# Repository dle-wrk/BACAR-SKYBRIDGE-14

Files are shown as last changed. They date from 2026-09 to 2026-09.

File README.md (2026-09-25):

# The BACAR Pyramid Payload

**AMSAT SA BACAR-14 "Skybridge" — 17 October 2026**
Contact: Christo Kriek, ZR6LJK — christo.kriek@live.co.za (subject "BACAR")

A natural-light Pepper's Ghost experiment for a high-altitude balloon flight.

---

## What it is trying to do

This payload uses the Earth itself as the light source for an optical illusion
called a Pepper's Ghost, so that a small camera inside a 100 mm cube records
what looks like a floating, three-dimensional image of the Earth below.

Most hologram-pyramid gadgets sit on a desk and reflect a bright video screen.
This one removes the screen entirely. Flown to 25–35 km, it points a single
opening downward at the bright, sunlit Earth. That view *is* the source. A
four-sided clear pyramid reflects it toward a camera, and the camera captures
a floating image formed from real light coming off the planet — no screen, no
power drawn for the image, just optics.

**The question behind it:** can a natural-light Pepper's Ghost capture a
recognisable Earth from the edge of space? Desk versions rely on darkness and
a bright screen. Here the conditions are inverted — the source is far away and
the surroundings are bright. Whether the effect still reads on camera is the
experiment. Success or not, the result is worth recording.

> **Not a hologram.** Real holography needs coherent laser light and
> interference patterns. A pyramid produces a reflection-based floating image —
> visually similar, physically different. "Hologram pyramid" is a popular but
> technically loose name.

---

## The optical principle

Two conditions make a Pepper's Ghost work, and both drive the whole design:

**A bright source against a dark background.** In reflection, black effectively
becomes invisible. Any background light that isn't part of the intended image
shows up as a faint grey box and ruins the illusion. This is why the interior
must be matte black and light-sealed.

**A specific viewpoint.** The floating image only exists when seen through the
reflecting face from the correct angle. The camera has to sit exactly where a
viewer's eye would — it cannot be placed anywhere and "look at the hologram",
because there is no free-floating image to photograph. It must look *at the
reflection in the pyramid face*.

---

## How light travels through the payload

| Step | What happens |
|---|---|
| **1. Entry** | Light from the sunlit Earth travels up through one round aperture in the floor — the only opening that admits image light. Sealed with a clear disc that still passes light. |
| **2. Reflection** | It strikes the inside of one clear acrylic pyramid face, which acts as a partial mirror. |
| **3. Redirection** | The angled face turns the upward light sideways, toward the camera. |
| **4. Capture** | The camera, tilted **18°**, looks at that face and records the floating image. |

### Why 18 degrees

The pyramid faces sit at **54°**, set by the shape of the pre-cut acrylic
panels. A mirror doubles any tilt, so a face 9° steeper than a plain 45° mirror
sends the reflected ray out **18° away from level**. The camera is angled 18°
to look straight back down that reflected path.

The number is forced by the pyramid's geometry, not chosen for looks.

### Why one aperture, not four

An earlier idea used four holes, one per face. It was set aside deliberately:

- **Four holes** — each face reflects a different direction, so the camera sees
  four unrelated views layered on top of each other. Busy, incoherent, and four
  openings to seal against the cold instead of one.
- **One aperture** — a single source produces one clean, coherent floating image
  of whatever is directly below, and only one opening needs sealing.

---

## Structure

A **100 × 100 × 100 mm cube** — the maximum size allowed for the flight — built
from flat panels of **3 mm black acrylic**, laser-cut and glued with acrylic
cement into a light-tight box. Black is essential, not cosmetic: it absorbs
stray light that would otherwise wash out the reflection.

### Panels

| Panel | Features |
|---|---|
| **Floor** | Round light aperture (offset, under the camera's line of sight), sealed clear window, four corner holes for the suspension line, slots locating the pyramid base |
| **Lid** | Pyramid-top support, suspension ring holes, corner string holes matching the floor so the load line runs straight through |
| **Four walls** | Solid and black. Only two carry openings — a small antenna hole, and mounting features for the camera bracket |

### Internal parts

- **The pyramid** — pre-cut four-sided clear acrylic frustum. Base ~85 mm,
  flat top ~9 mm, faces at 54°. Sits base-down on the floor, tip up.
- **Pyramid mounts** — four base clips locate the base; a top support slots
  into the lid and captures the 9 mm tip. Held at both ends.
- **Camera bracket** — two triangular brackets with an 18° top edge, plus a
  flat plate the camera screws to.
- **Electronics** — ESP32-CAM recording to its own card, nRF24 radio,
  MT3608 boost converter, 18650 lithium cell.

**Mass: ~385 g** against a 500 g limit.

---

## Designing for the environment

At 25–35 km the air is thin and temperature falls to around **−50 to −60 °C**.
The payload can't be recovered mid-flight, so it must survive unattended.

**Cold.** The electronics and battery are rated for far milder temperatures
than they'll meet. The box is insulated, a hand-warmer adds heat, and a
silica-gel sachet removes moisture that would otherwise freeze inside.

**Frost.** As the box cools, trapped moisture condenses and can freeze on the
pyramid and lens — directly in the optical path. The sealed window keeps damp
air out; anti-fog treatment helps; keeping the interior warm and dry is the
real defence.

**Landing.** The payload returns under parachute at several metres per second.
Acrylic is brittle in the cold, so glued joints and mounts must take the
impact. Drop-test before flight.

---

## ⚠ Three things that need resolving

These are conflicts between this document and what's currently built. They
are not cosmetic.

### 1. "Airtight" will destroy the box

A sealed enclosure at 30 km carries roughly **1 bar of pressure differential**.
On a 100 × 100 mm panel that's about **1000 N — 100 kgf pushing outward on
every face.** Glued 3 mm acrylic will not hold that, and if it fails it fails
explosively, taking the optics with it.

The frost argument for sealing is real, but the pressure problem is fatal.
The standard resolution is to **vent, but slowly**: a small hole with a
tortuous or filtered path, plus the silica gel already planned. Air equalises
gradually; moist air doesn't rush in. Do not fly this genuinely airtight.

### 2. The 3D-printed enclosure is now obsolete

`holocube.py`, `holocube_fitcheck.py` and the exported STL/STEP files describe
a **printed** cube with the camera on-axis looking down the pyramid's centre.
This document describes a **laser-cut acrylic** cube with the camera tilted
18° looking at a face from the side. They are different machines.

Nothing is lost by keeping the files, but don't print from them expecting the
optics in this document.

### 3. Radio: beacon or downlink?

This document calls the nRF24 "a short-range beacon for recovery". The firmware
currently streams telemetry images over it as well. The streaming version also
functions as a beacon, so there's no conflict in practice — but if the intent
really is beacon-only, the image transmission can be disabled and the cycle
gets shorter.

---

## The flight cycle (~48 s, repeats forever)

```
1. 15 s video clip        -> SD card
2. 1x high-res photo      -> SD card   (UXGA master)
3. 1x low-res photo       -> SD card + streamed over nRF24
4. 30 s pause
```

At 5 m/s ascent that's a full snapshot every **~240 m**, about 125 samples on
the way to 30 km. Set `pause_sec=42` in the config for a 60 s cycle and
exactly 300 m per sample.

| | 3-hour flight |
|---|---|
| Card usage | ~383 MB |
| Average current | ~162 mA |
| Battery used | ~7% of 12 Ah |

Video rolls 15 s out of every 48, so there's roughly a **31% chance of catching
the burst on video**.

### Packet format (32 bytes)

```
[0] type   [1] fragment   [2..31] 30 bytes payload
```

Integrity is the nRF24's **hardware CRC-16** — corrupt packets never arrive.
The end-of-image CRC tells the receiver whether the *reassembly* was complete,
which is a different question. nRF24 carries raw packets, not MQTT; MQTT lives
at mission control, on the far side of the relay.

---

## Pin map — SD and nRF24 share one SPI bus

The camera claims almost every GPIO. These six are all that remain.
**Do not use `SD_MMC`** — it wants these same pins.

| Signal | GPIO |
|---|---|
| SCK | 14 |
| MOSI | 15 |
| MISO | 2 |
| SD chip-select | 13 |
| nRF24 CSN | 12 |
| nRF24 CE | 4 |

---

## Things that will destroy hardware

- **nRF24 VCC → 3V3, never 5V.** No regulator on the module.
- **Set the MT3608 to 5.0 V with a multimeter before connecting the ESP32.**
  It does not ship at 5 V.
- **10 kΩ from IO12 to GND.** Strapping pin — high at boot means the chip
  picks the wrong flash voltage and won't start at all.
- **Capacitor stripe → GND.** Electrolytics vent if reversed.
- **Black tape over the flash LED.** IO4 doubles as that LED and would flood
  the optical chamber on every transmission.

---

## Files

| File | What it is |
|---|---|
| `holocube_selftest/` | **Upload this first.** Checks camera, PSRAM, SD, radio. |
| `holocube_esp32cam/` | Flight firmware. |
| `holocube_receiver_uno/` | Ground receiver for an Arduino Uno. |
| `holocube_rebuild.py` | Reassembles JPEGs from the receiver's serial stream. |
| `holocube.cfg` | **Copy to the SD card root.** Tune exposure and timing without reflashing. |
| `SOLDERING.md` | Bench checklist with three test points. |
| `holocube.py` | *Superseded* — FreeCAD builder for the printed enclosure. |
| `holocube_fitcheck.py` | *Superseded* — collision check for the printed enclosure. |

---

## The honest unknown

The enclosure is the easy part. The box, mounts, sealing and mass budget are
all solved on paper. The single thing that decides whether the payload succeeds
is whether a natural-light Pepper's Ghost actually produces a recognisable
floating Earth on camera — and that cannot be answered by design alone.

**The critical step before committing to the flight is a ground test.** Put the
camera in its mount, aim the sealed aperture at a bright scene with depth, and
record. If the floating image reads on the ground, it will read from altitude.
If it doesn't, that's discovered cheaply on a bench instead of expensively at
30 km.

### Test order

- [ ] **Optical bench test** — does the ghost read at all?
- [ ] **Focus the lens at infinity**, lock it with nail varnish
- [ ] **Tune `aec`** in `holocube.cfg` — exposure is locked and 300 is a guess
- [ ] **Full-duration run** — the whole flight time, armed, exactly as it flies
- [ ] **Freezer test** — one hour assembled and armed
- [ ] **Drop test** — acrylic is brittle cold

On a high-altitude flight, **cold, power and landing cause far more failures
than the optics ever will.** Test in that order.

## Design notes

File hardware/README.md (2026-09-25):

# Skybridge hardware / CAD

FreeCAD scripts that build the printed cube parts as solids and validate
component fit. Run from inside the FreeCAD Python console.

## Scripts

**`holocube.py`** — builds all three printed parts as true solids, exports
STL (print-oriented) and STEP into the parent directory.

```
exec(open(r"C:\path\to\Skybridge14\hardware\holocube.py").read())
```

**`holocube_fitcheck.py`** — drops dimensionally-accurate stand-ins (ESP32-CAM,
NRF24, 18650, boost converter, perspex panels) into the assembly so collisions
and clearances can be sanity-checked. Run **after** `holocube.py`.

```
exec(open(r"C:\path\to\Skybridge14\hardware\holocube_fitcheck.py").read())
```

## Note on output paths

`holocube.py` currently writes STL/STEP to a hardcoded absolute path
(`OUT = r"C:\Users\Dylan\Videos\skybridge14"`). If you clone this on another
machine, change that constant to somewhere writable before running.

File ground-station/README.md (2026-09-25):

# Skybridge ground-station tools

Python scripts that run on the base-station laptop (not in the deployed web app).
They bridge the NRF24 radio link, the MQTT broker the web dashboard subscribes
to, and (via a separate audio-capture path) external SSTV transmissions heard
on the radio.

## Scripts

**`holocube_rebuild.py`** — reads the hex packet stream from the Uno receiver on
serial, reassembles low-res JPEGs, writes them to `rx_images/`, and (optionally)
publishes each image and STATUS heartbeat to MQTT so the Skybridge web app and
downstream tools see them.

**`holocube_sstv_rx.py`** — SSTV audio receiver. Captures audio from a chosen
laptop input device (mic, line-in, or a WASAPI loopback of what's playing to
the speakers) and saves rolling 60-second WAV files to `sstv_rx/`. Publishes
`sstv/status` so the web dashboard's SSTV tab reflects what's coming in. Feed
the saved WAVs into MMSSTV / QSSTV / an online decoder to recover the images.

**Skybridge cubes do NOT transmit SSTV.** This tool exists so the base station
can monitor *external* SSTV sources — pico balloons, ISS SSTV events, HAMs on
the pass.

**`holocube_sstv.py`** — SSTV **encoder** (legacy). Takes a JPEG and produces
SSTV audio for transmission. Kept for testing but not part of the mission-day
flow. Subscribes to cube image topics if you want to *send* an image out on the
air; skip it if you only want to receive.

## Install

```bash
pip install pyserial paho-mqtt pysstv Pillow sounddevice soundfile numpy
```

`sounddevice` ships PortAudio bundled on Windows — no separate install.

## Typical live loop (receive-only)

```bash
# terminal 1 — reassemble incoming NRF images from the Uno
python ground-station/holocube_rebuild.py COM8 --mqtt broker.emqx.io

# terminal 2 — capture external SSTV audio from the laptop speakers
python ground-station/holocube_sstv_rx.py --broker broker.emqx.io --loopback
```

Chain:

```
ESP32-CAM → NRF24 → UNO → serial → holocube_rebuild.py → MQTT → web dashboard
                                                                    ▲
                            radio → laptop audio → holocube_sstv_rx.py
                                                    (rolling WAV, MQTT status)
```

## Audio device selection

`holocube_sstv_rx.py` supports three ways to pick the input:

1. **Default input** (no flag). Whatever Windows uses as the default recording
   device — usually the built-in mic.
2. **--loopback** (Windows). Record what's playing to the laptop speakers via
   WASAPI loopback. Handy for capturing audio from an SDR web receiver or an
   audio-over-USB radio interface without any cable routing.
3. **--device "<name>"**. Partial-match a device by name. Run `--list-devices`
   first to see everything sounddevice can enumerate. Useful for things like
   VB-CABLE Output or a specific USB audio interface.

See each script's `--help` for full options.

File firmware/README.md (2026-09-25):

# Skybridge firmware

Arduino sketches for the flight and ground hardware. Each sketch lives in its
own folder because Arduino IDE requires the `.ino` filename to match the parent
folder name.

## Sketches

**`holocube_esp32cam/`** — flight firmware for the ESP32-CAM (AI-Thinker) payload.
Runs the 48-second cycle: 15 s video → SD, 1 hi-res photo → SD, 1 lo-res photo →
SD + NRF24, 30 s pause. Board: **AI Thinker ESP32-CAM**. Partition: **Huge APP
(3 MB No OTA / 1 MB SPIFFS)**. Libraries: `RF24` (TMRh20), `esp32` core.

**`holocube_receiver_uno/`** — ground-station NRF24 receiver on Arduino Uno.
Prints each good packet as hex on serial for [`ground-station/holocube_rebuild.py`](../ground-station/holocube_rebuild.py)
to reassemble. Board: **Arduino Uno**. Libraries: `RF24` (TMRh20).

**`holocube_selftest/`** — subsystem probe. Upload **before** the main sketch on
either board when something isn't working — it isolates SD, camera, NRF24, and
supply issues so you know which one is broken instead of guessing.

## Flashing the ESP32-CAM

If you don't have an FTDI or the ESP32-CAM programmer board, the Uno can act as
a USB-to-serial adapter. Wire:

- **UNO RESET → GND** (parks the ATmega so its USB-serial chip talks straight
  through to the ESP)
- **UNO 5V → ESP 5V** (only if the payload's boost converter is disconnected)
- **UNO GND → ESP GND**
- **UNO D0 → ESP U0R** via a 220 Ω/330 Ω divider (or just a 1 kΩ series resistor
  as a rough current limit — the ESP's ESD clamp diodes handle the rest)
- **UNO D1 → ESP U0T** direct
- **ESP IO0 → GND** (enters bootloader mode)

Then in Arduino IDE pick `AI Thinker ESP32-CAM`, the Uno's COM port, and press
the ESP's RESET button the moment esptool prints `Connecting……`.

See `SOLDERING.md` at the project root for hardware assembly.

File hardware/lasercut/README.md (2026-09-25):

# Lasercut acrylic parts

FreeCAD sources for every laser-cut piece of the payload, plus the flat DXF
exports the laser cutter actually consumes.

## What's here

- `*.FCStd` — FreeCAD source per part (the authoritative model)
- `BACAR_lasercut.FCStd` — combined assembly
- `BACAR_lasercut.FCMacro` — Python macro that regenerates all outputs
- `BACAR_lasercut.pdf` — drawings / cut sheet for reference
- `dxf/*.dxf` — flat DXFs, one per part — this is what you send to the laser

## What's NOT here (regenerate from FreeCAD when needed)

DWG, STEP, STL, and the `BACAR_DXF_LASER_CUT.zip` bundle are derived outputs
of the `.FCStd` sources — kept out of the repo to reduce bloat. Regenerate any
you need from the FreeCAD file or the macro.

## FreeCAD backups

`.FCBak` files are FreeCAD's own timestamped auto-backups. They're gitignored
at the repo root (`*.FCBak`). Don't commit them.

## Parts overview

| File | Purpose |
| --- | --- |
| `LID.FCStd` | Top plate — pyramid seats on this |
| `FLOOR.FCStd` | Bottom plate — battery, boost converter, electronics |
| `WALL_L.FCStd`, `WALL_R.FCStd` | Side walls |
| `WALL_CAM.FCStd`, `WALL_NRF.FCStd` | Walls with camera / NRF antenna cutouts |
| `CAM_PLATE.FCStd` | ESP32-CAM mounting plate |
| `CAM_TRI_1.FCStd`, `CAM_TRI_2.FCStd` | Camera-plate triangles |
| `PYR_BASE_CLIP_1..4.FCStd` | Four clips holding the perspex pyramid base |
| `PYRAMID_TOP_SUPPORT.FCStd` | Tip support for the pyramid |

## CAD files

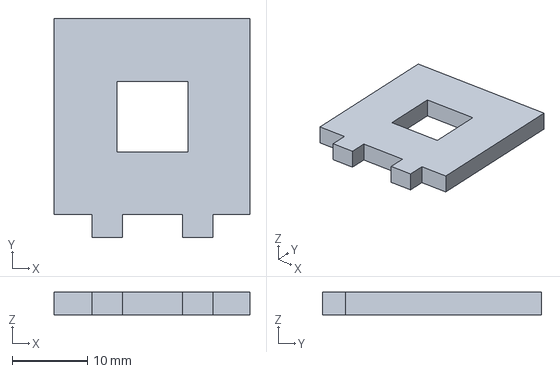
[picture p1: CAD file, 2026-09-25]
hardware/lasercut/PYRAMID_TOP_SUPPORT.FCStd
26.0 x 29.0 x 3.00 mm

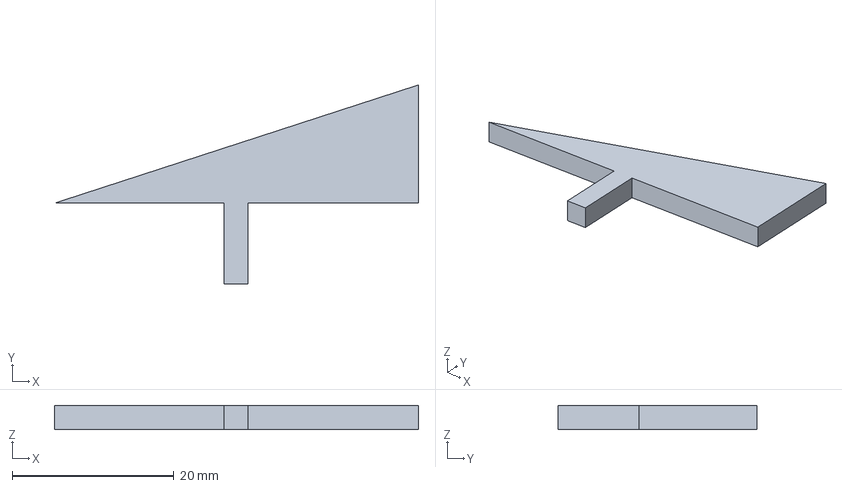
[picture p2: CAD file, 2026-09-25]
hardware/lasercut/CAM_TRI_1.FCStd
45.0 x 24.6 x 3.00 mm

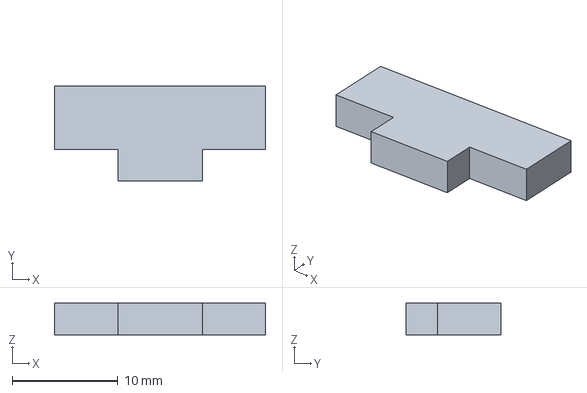
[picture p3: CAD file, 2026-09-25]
hardware/lasercut/PYR_BASE_CLIP_2.FCStd
20.0 x 9.00 x 3.00 mm

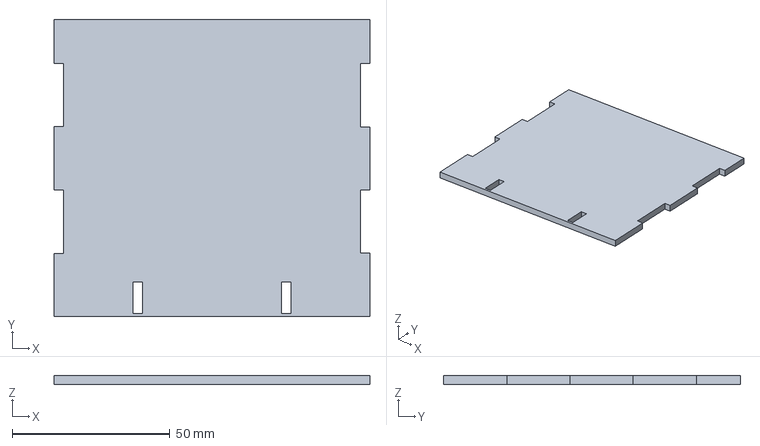
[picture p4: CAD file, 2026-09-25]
hardware/lasercut/WALL_CAM.FCStd
100.0 x 94.0 x 3.00 mm

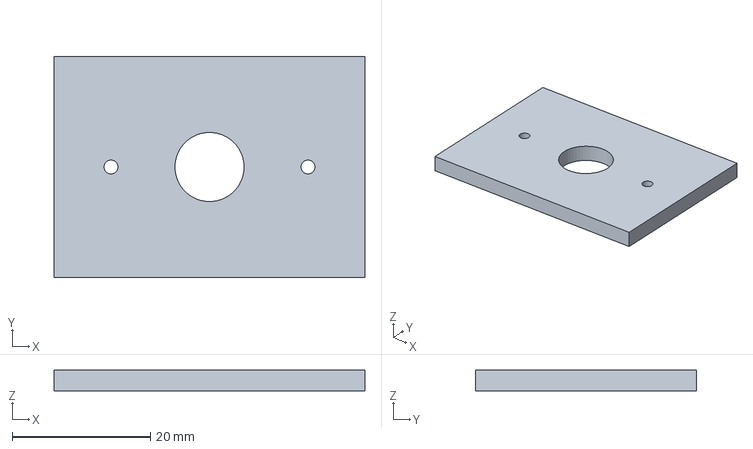
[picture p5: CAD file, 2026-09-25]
hardware/lasercut/CAM_PLATE.FCStd
45.0 x 32.0 x 3.00 mm

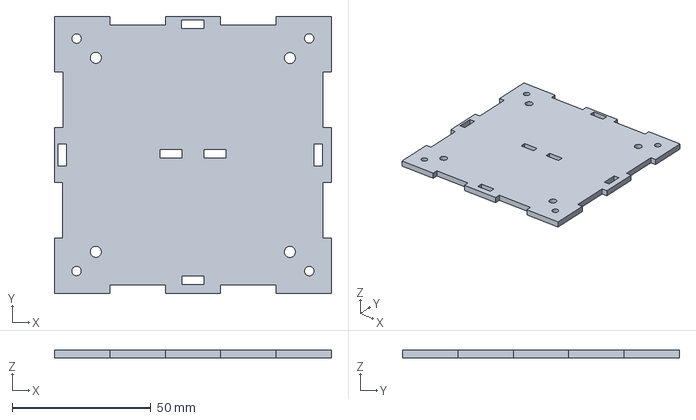
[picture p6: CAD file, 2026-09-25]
hardware/lasercut/LID.FCStd
100.0 x 100.0 x 3.00 mm

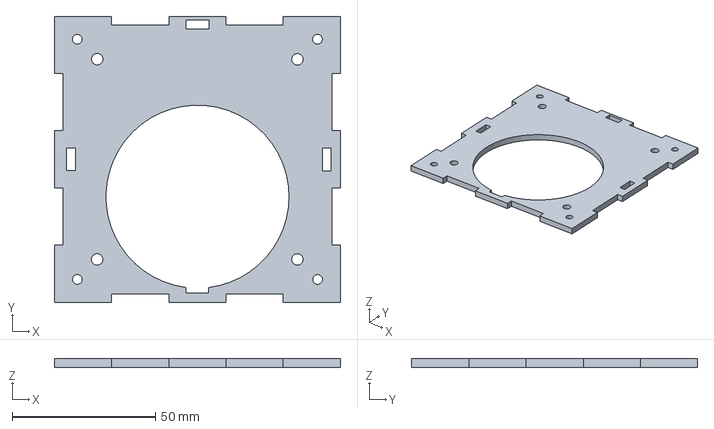
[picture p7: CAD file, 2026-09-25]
hardware/lasercut/FLOOR.FCStd
100.0 x 100.0 x 3.00 mm

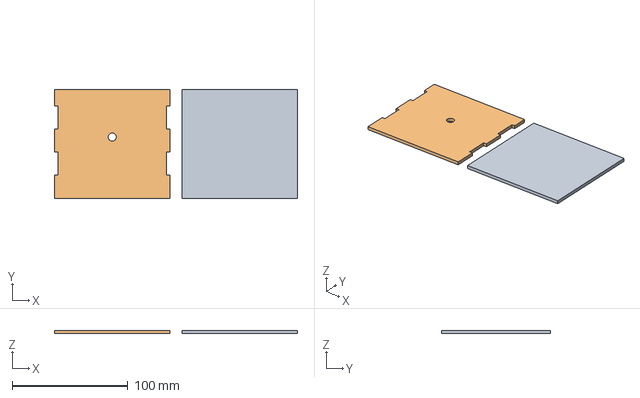
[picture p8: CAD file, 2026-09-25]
hardware/lasercut/WALL_NRF.FCStd
210.3 x 94.0 x 3.00 mm
WALL_NRF

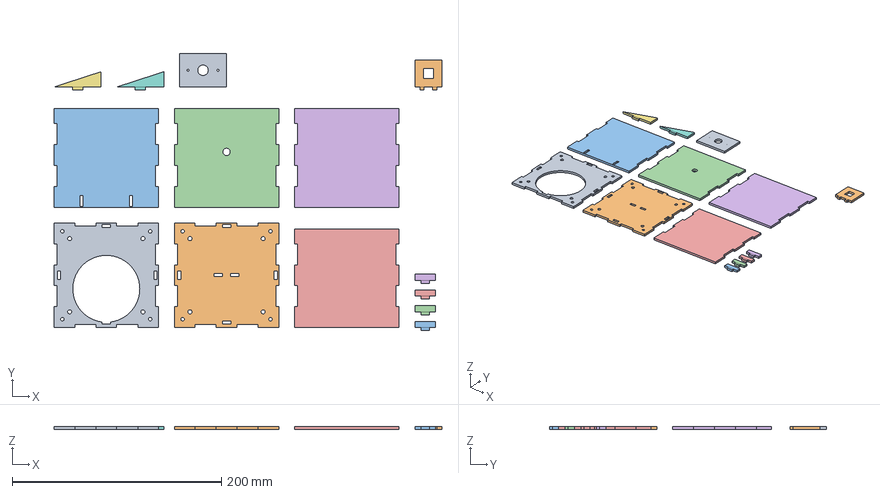
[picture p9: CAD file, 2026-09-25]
hardware/lasercut/BACAR_lasercut.FCStd
371.0 x 264.8 x 2.80 mm
FLOOR
LID
WALL_CAM
WALL_NRF
WALL_L
WALL_R
CAM_TRI_1
CAM_TRI_2
CAM_PLATE
PYRAMID_TOP_SUPPORT
PYR_BASE_CLIP_1
PYR_BASE_CLIP_2
PYR_BASE_CLIP_3
PYR_BASE_CLIP_4

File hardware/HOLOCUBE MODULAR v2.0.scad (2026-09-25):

// ============================================================
// HOLOCUBE  —  AMSAT SA BACAR-14 "Skybridge"  —  17 Oct 2026
// 98mm cube. Pepper's Ghost sky-combiner.
// THREE printed parts: PLATE / BODY / LID, 8x M3 self-tappers.
// Rides freely on the train line through 4 corner straws.
//
// FLIES WIDE END DOWN. Camera looks down through the pyramid.
// PRINT PLATE + BODY IN BLACK. PETG if you have it.
// WRAP THE LID ONLY, outside, in space blanket.
// ============================================================

PART = "ALL";   // "ALL" | "PLATE" | "BODY" | "LID" | "LAYOUT"

CELLS   = 1;      // 1 = needs MT3608 boost.  2 = series + 3 diodes.

// ---- perspex (measured) ----
W_BASE  = 85;
W_TOP   = 9;
EDGE    = 75;
PANEL_T = 3;      // <<< MEASURE YOURS

// ---- airframe ----
CUBE    = 98;
WALL    = 2;
PLATE_T = 3;
SPLIT   = 58;
LIP_H   = 6;
RIM_H   = 11;

NADIR_R = 15;     // <<< print spare plates at 12 / 15 / 20
WIN_W   = 70;
WIN_H   = 42;

// ---- corner straws ----
STRAW_C = 44.5;
TUBE_R  = 4.5;
STRAW_R = 3.0;

// ---- screws: 8x M3 self-tapping ----
SCREW_C    = 46;
LIDSCREW_Z = 61;

// ---- internal stack ----
BRKT_Z   = 63;
TROUGH_Z = 82;

// ---- derived ----
DR      = (W_BASE - W_TOP)/2;
H_PLANE = sqrt(EDGE*EDGE - DR*DR);
FRUS_H  = sqrt(H_PLANE*H_PLANE - DR*DR);
SEAT_Z  = PLATE_T;
APEX    = SEAT_Z + FRUS_H;
TILT    = 180 - atan(FRUS_H/DR);
$fn     = 40;

echo(str("face ", atan(FRUS_H/DR), " deg | apex z=", APEX,
         " | cells ", CELLS));

if (PART == "ALL")    { plate(); body(); lid(); pyramid(); }
if (PART == "PLATE")    plate();
if (PART == "BODY")     translate([0,0,-PLATE_T]) body();
if (PART == "LID")      translate([0,0,-SPLIT]) lid();
if (PART == "LAYOUT") {
    translate([-55,-55,0]) plate();
    translate([ 55,-55,0]) translate([0,0,-PLATE_T]) body();
    translate([  0, 55,0]) rotate([180,0,0]) translate([0,0,-CUBE]) lid();
}

// ============================================================
// SHARED
// ============================================================
module pyramid_solid(cl) {
    for (a=[0:90:270]) rotate([0,0,a])
      translate([0, W_BASE/2, SEAT_Z]) rotate([TILT,0,0])
        translate([0,0,-cl])
          linear_extrude(PANEL_T + 2*cl)
            offset(delta=cl)
              polygon([[-W_BASE/2,0],[W_BASE/2,0],
                       [W_TOP/2,H_PLANE],[-W_TOP/2,H_PLANE]]);
}
module pyramid() { color([0.55,0.78,1.0,0.28]) pyramid_solid(0); }

module straw_bores(z0,h) {
    for (x=[-STRAW_C,STRAW_C]) for (y=[-STRAW_C,STRAW_C])
      translate([x,y,z0]) cylinder(h=h, r=STRAW_R);
}

// ============================================================
// PART 1 — BASE PLATE
// ============================================================
module plate() {
  color([0.30,0.30,0.33])
  difference() {
    linear_extrude(PLATE_T) square([CUBE,CUBE], center=true);

    translate([0,0,-1]) cylinder(h=PLATE_T+2, r=NADIR_R);

    // straw bores with lead-in chamfer
    for (x=[-STRAW_C,STRAW_C]) for (y=[-STRAW_C,STRAW_C])
      translate([x,y,-1]) {
          cylinder(h=PLATE_T+2, r=STRAW_R);
          cylinder(h=2.5, r1=STRAW_R+1.5, r2=STRAW_R);
      }

    // screw clearance + countersink (flush underside)
    for (a=[0:90:270]) rotate([0,0,a])
      translate([0,SCREW_C,-1]) {
          cylinder(h=PLATE_T+2, r=1.7);
          cylinder(h=2.7, r1=3.2, r2=1.7);
      }
  }
}

// ============================================================
// PART 2 — BODY
// ============================================================
module body() {
  color([0.25,0.25,0.28])
  difference() {
    union() {
        // walls
        difference() {
            translate([0,0,PLATE_T])
              linear_extrude(SPLIT-PLATE_T) square([CUBE,CUBE], center=true);
            translate([0,0,PLATE_T-1])
              linear_extrude(SPLIT-PLATE_T+2)
                square([CUBE-2*WALL, CUBE-2*WALL], center=true);
        }

        // corner straw tubes
        for (x=[-STRAW_C,STRAW_C]) for (y=[-STRAW_C,STRAW_C])
          translate([x,y,PLATE_T]) cylinder(h=SPLIT-PLATE_T, r=TUBE_R);

        // locating rim: seats the pyramid, carries the plate screws
        translate([0,0,PLATE_T])
          linear_extrude(RIM_H)
            difference() {
                square([94,94], center=true);
                square([87,87], center=true);
            }

        // alignment lip for the lid
        translate([0,0,SPLIT-1])
          linear_extrude(LIP_H+1)
            difference() {
                square([92,92], center=true);
                square([88,88], center=true);
            }

        // bosses for the lid screws, on the inner face of the lip
        for (a=[0:90:270]) rotate([0,0,a])
          translate([0,43,LIDSCREW_Z]) cube([12,6,10], center=true);
    }

    // guarantee clearance around the perspex everywhere
    pyramid_solid(0.6);

    // light windows
    for (a=[0:90:270]) rotate([0,0,a])
      translate([0, CUBE/2, 30]) cube([WIN_W, 12, WIN_H], center=true);

    // plate screw pilots, blind, from below
    for (a=[0:90:270]) rotate([0,0,a])
      translate([0,SCREW_C,PLATE_T-1]) cylinder(h=9, r=1.25);

    // lid screw pilots, horizontal
    for (a=[0:90:270]) rotate([0,0,a])
      translate([0,43,LIDSCREW_Z]) rotate([90,0,0])
        cylinder(h=8, r=1.25, center=true);

    straw_bores(PLATE_T-1, SPLIT+LIP_H);
  }
}

// ============================================================
// PART 3 — LID   (all electronics)
// ============================================================
module lid() {
  color([0.72,0.80,0.95])
  difference() {
    union() {
        difference() {
            translate([0,0,SPLIT])
              linear_extrude(CUBE-SPLIT) square([CUBE,CUBE], center=true);
            translate([0,0,SPLIT])
              linear_extrude(CUBE-SPLIT-WALL)
                square([CUBE-2*WALL, CUBE-2*WALL], center=true);
        }

        for (x=[-STRAW_C,STRAW_C]) for (y=[-STRAW_C,STRAW_C])
          translate([x,y,SPLIT]) cylinder(h=CUBE-SPLIT, r=TUBE_R);

        // pyramid clamp collar — FIT A FOAM PAD ON THE LOWER FACE
        translate([0,0,APEX+0.5])
          difference() {
              cylinder(h=BRKT_Z-APEX-0.5, r1=9, r2=12);
              translate([0,0,-1])
                cylinder(h=BRKT_Z-APEX+1.5, r1=4.3, r2=8.5);
          }

        // camera bracket
        translate([0,0,BRKT_Z]) linear_extrude(2) square([38,50], center=true);
        for (a=[0:90:270]) rotate([0,0,a])
          translate([0,32,BRKT_Z+1]) cube([30,30,2], center=true);

        // 18650 trough(s) with cable-tie slots
        for (i=[0:CELLS-1]) {
          yy = (CELLS==1) ? 28 : (i==0 ? -34 : 34);
          translate([0,yy,TROUGH_Z]) {
            difference() {
                cube([68,22,20], center=true);
                rotate([0,90,0]) cylinder(h=70, r=9.4, center=true);
                translate([0,0,8]) cube([70,18,10], center=true);
            }
            for (dx=[-22,22]) translate([dx,0,0])
              difference() {
                  cube([4,26,20], center=true);
                  cube([6,22,22], center=true);
              }
          }
        }

        // NRF24 slot
        for (dx=[-2,2])
          translate([32+dx,-16,74]) cube([1.6,30,16], center=true);

        // wiring loom anchors
        for (a=[0:90:270]) rotate([0,0,a])
          translate([44,20,SPLIT+2]) cube([4,3,10], center=true);
    }

    straw_bores(SPLIT-1, CUBE-SPLIT+2);

    // straw lead-in at the top exit
    for (x=[-STRAW_C,STRAW_C]) for (y=[-STRAW_C,STRAW_C])
      translate([x,y,CUBE-2.5]) cylinder(h=3, r1=STRAW_R, r2=STRAW_R+1.5);

    // lens bore through bracket
    translate([0,0,BRKT_Z-1]) cylinder(h=5, r=9);

    // lid screw clearance, horizontal (pan-head, sits proud)
    for (a=[0:90:270]) rotate([0,0,a])
      translate([0,CUBE/2+1,LIDSCREW_Z]) rotate([90,0,0])
        cylinder(h=9, r=1.7);

    // keyring / safety tether holes
    for (x=[-34,34]) for (y=[-34,34])
      translate([x,y,CUBE-12]) cylinder(h=14, r=2.5);

    // pressure vents
    for (a=[0:90:270]) rotate([0,0,a])
      for (x=[-16,16])
        translate([x, CUBE/2, 93]) rotate([90,0,0])
          cylinder(h=12, r=2, center=true);

    // arming switch port
    translate([0,-CUBE/2,68]) cube([16,10,10], center=true);
  }
}

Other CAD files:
hardware/lasercut/CAM_TRI_2.FCStd
hardware/lasercut/WALL_L.FCStd
hardware/lasercut/WALL_R.FCStd
hardware/lasercut/PYR_BASE_CLIP_1.FCStd
hardware/lasercut/PYR_BASE_CLIP_3.FCStd
hardware/lasercut/PYR_BASE_CLIP_4.FCStd
hardware/lasercut/dxf/CAM_PLATE.dxf
hardware/lasercut/dxf/CAM_TRI_1.dxf
hardware/lasercut/dxf/CAM_TRI_2.dxf
hardware/lasercut/dxf/FLOOR.dxf
hardware/lasercut/dxf/LID.dxf
hardware/lasercut/dxf/PYRAMID_TOP_SUPPORT.dxf
hardware/lasercut/dxf/PYR_BASE_CLIP_1.dxf
hardware/lasercut/dxf/PYR_BASE_CLIP_2.dxf
hardware/lasercut/dxf/PYR_BASE_CLIP_3.dxf
hardware/lasercut/dxf/PYR_BASE_CLIP_4.dxf
hardware/lasercut/dxf/WALL_CAM.dxf
hardware/lasercut/dxf/WALL_L.dxf
hardware/lasercut/dxf/WALL_NRF.dxf
hardware/lasercut/dxf/WALL_R.dxf

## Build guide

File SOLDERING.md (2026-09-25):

# HOLOCUBE — Soldering checklist

Work through this in order. There are three test points; **do not skip them.**
The whole point of the order is that if something is wrong you have five wires
to check, not fifteen.

---

## Before you heat the iron

- [ ] **Set the MT3608 to 5.0 V.** Cell → boost IN+/IN−, multimeter on OUT+/OUT−.
      Turn the trimpot until it reads **5.00 V**. It is a multi-turn pot, so expect
      to keep going a while before the voltage moves. It does **not** ship at 5 V,
      and connecting it blind can put 15–20 V into the ESP32 and kill it instantly.
- [ ] Black tape over the flash LED next to the camera lens.
- [ ] Confirm the switch is **latching**, not momentary. Press and release: it must
      stay down. If it springs back, it won't work as a power switch.

---

## STEP 1 — Power chain (5 wires)

| # | From | To | Colour | Length |
|---|---|---|---|---|
| 1 | Holder **red +** | Switch, pin A | red | 100 mm |
| 2 | Switch, pin B | Boost **IN+** | red | 100 mm |
| 3 | Holder **black −** | Boost **IN−** | black | 80 mm |
| 4 | Boost **OUT+** | ESP32 **5V** | red | 60 mm |
| 5 | Boost **OUT−** | ESP32 **GND** | black | 60 mm |

On a 4-pin switch the pins are two internally-joined pairs. Find them with a
continuity tester and use **one pin from each pair**. Wire across a pair and
you've made a permanent short.

### ✅ TEST POINT 1
Switch on. Multimeter on the ESP32's **5V and GND pins**. Must read **5.0 V**.
Switch off — must read 0 V. Do not continue until both are true.

---

## STEP 2 — Capacitors on the ESP32

- [ ] 2–3 × 10 µF in parallel across ESP32 **5V and GND**, short legs, at the board.
- [ ] **Striped leg goes to GND.** Backwards, electrolytics vent.

---

## STEP 3 — Programming pigtail (4 wires, NOT soldered to the Uno)

80 mm each, ending in a female header you can tuck inside the lid.

| Wire | ESP32 pin | Plugs to |
|---|---|---|
| 1 | **U0T** | Uno D1 |
| 2 | **U0R** | Uno D0 |
| 3 | **GND** | Uno GND |
| 4 | **GPIO0** | bare tinned end — touch to GND to arm the bootloader |

**No 5 V wire to the Uno. Ever.** The battery powers the ESP32 now; the Uno
supplies serial only. Two supplies fighting is how boards die.

### ✅ TEST POINT 2 — the important one
Plug in the Uno. Battery **on**. Upload `holocube_selftest`.

Ground GPIO0 → press RST → click Upload → release GPIO0 when it finishes.

You should get the numbered pass/fail list. `[7] NRF24 not fitted yet` is
expected. **Get a successful upload here before soldering anything else.**

Powering from the battery instead of the Uno should also cure the
`serial noise` / `no more data` errors — the MT3608 is a far stiffer supply
than the Uno's 5 V pin.

---

## STEP 4 — Radio (7 wires + 1 resistor + caps)

Only once STEP 3 uploads cleanly.

| # | From | To | Length |
|---|---|---|---|
| 6 | ESP32 **3V3** | NRF24 **VCC** | 60 mm |
| 7 | ESP32 **GND** | NRF24 **GND** | 60 mm |
| 8 | ESP32 **IO14** | NRF24 **SCK** | 60 mm |
| 9 | ESP32 **IO15** | NRF24 **MOSI** | 60 mm |
| 10 | ESP32 **IO2** | NRF24 **MISO** | 60 mm |
| 11 | ESP32 **IO12** | NRF24 **CSN** | 60 mm |
| 12 | ESP32 **IO4** | NRF24 **CE** | 60 mm |

- [ ] **10 kΩ from IO12 to GND.** Strapping pin — if it's high at boot the chip
      picks the wrong flash voltage and won't start at all. Skip this and you
      get a board that appears dead.
- [ ] 2–3 × 10 µF across NRF24 **VCC and GND**, soldered onto the module pins
      themselves, legs as short as possible.
- [ ] NRF24 **IRQ** stays unconnected.

**NRF24 VCC goes to 3V3, never 5V.** The module has no regulator. 5 V kills it
instantly, and this is the most common way people destroy them.

### ✅ TEST POINT 3
Re-upload `holocube_selftest`. Now `[7] NRF24` should read **ok**.

---

## STEP 5 — Tidy

- [ ] Cable-tie the loom to the four anchor posts at the lid base.
- [ ] Cable-tie the holder to the shelf (2 ties through the slots).
- [ ] A third tie **around the cell and holder together**, so the cell can't
      lift off its spring contacts under vibration. This is the top-ranked
      failure mode for the whole payload.
- [ ] Foam-tape the MT3608 to the underside of the shelf.
- [ ] Cable-tie the programming pigtail so it can't rattle, header reachable.

---

## The four that destroy hardware

1. NRF24 VCC → **3V3**, never 5 V.
2. Boost set to **5.0 V** before it touches the ESP32.
3. Capacitor **stripe → GND**.
4. **10 kΩ IO12 → GND**, or it won't boot.

---

## Wire count

12 permanent + 4 pigtail + 1 resistor + 4–6 capacitors.
Roughly 900 mm of wire total.

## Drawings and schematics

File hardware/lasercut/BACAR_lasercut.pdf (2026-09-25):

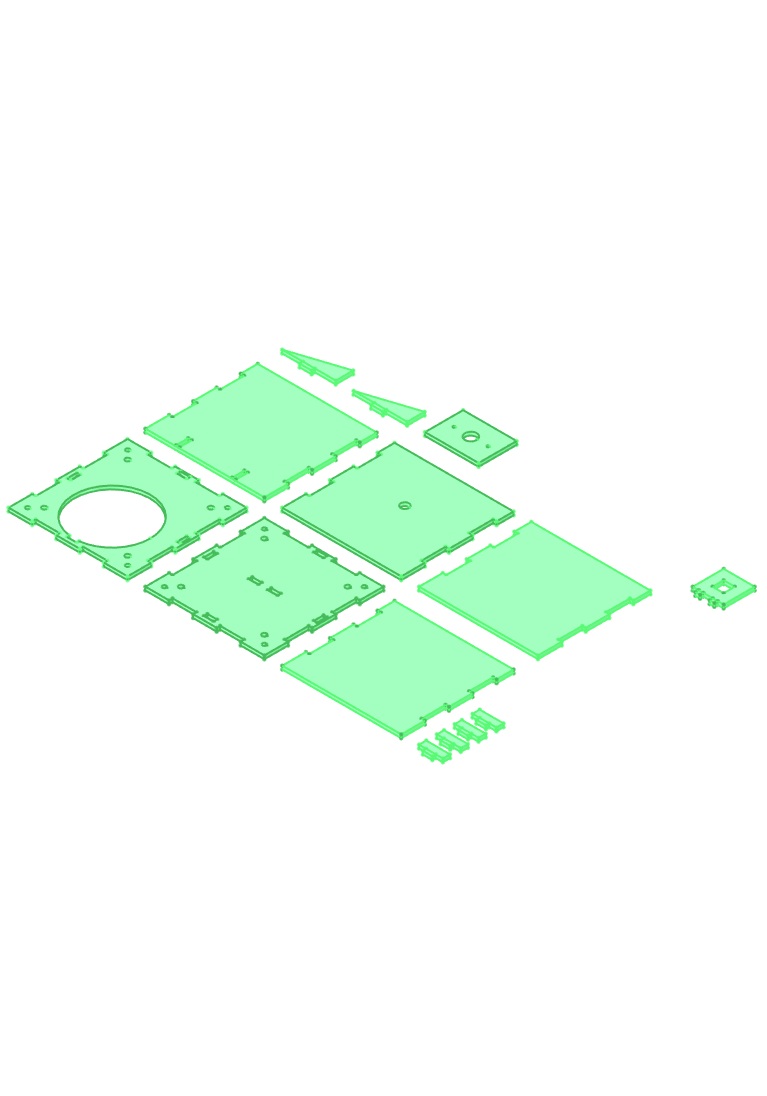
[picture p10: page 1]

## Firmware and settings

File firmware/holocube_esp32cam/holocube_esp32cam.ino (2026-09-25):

/* ============================================================
   HOLOCUBE  —  AMSAT SA BACAR-14 "Skybridge"  —  17 Oct 2026
   ESP32-CAM (AI-Thinker) payload firmware

   Pepper's Ghost sky-combiner. Camera looks DOWN through the
   pyramid; the four perspex panels reflect the limb into frame.

   THE CYCLE  (~48 s, repeats forever)
     1. 15 s video clip            -> SD card
     2. 1x high-res photo          -> SD card  (the master)
     3. 1x low-res photo           -> SD card + streamed over NRF24
     4. 30 s pause

   WHY IT'S BUILT THIS WAY
     - SD card is the PRIMARY record. Radio is the demo. If the
       link fails you still recover every frame on landing.
     - Nothing halts. A dead subsystem is logged and skipped.
     - Files are closed after every write. Power loss costs one
       frame, not the card.
     - Exposure is LOCKED. Auto-exposure meters on the bright
       nadir disc and crushes the ghost arcs to black.
     - Sensor resolution changes twice per cycle, with discard
       frames after each switch. The first frame after a
       framesize change is unreliable.

   TUNING WITHOUT REFLASHING
     Put a file called holocube.cfg in the root of the SD card:
         aec=300
         gain=0
         hi_quality=10
         lo_quality=18
         video_sec=15
         pause_sec=30
     Missing file or bad lines -> compiled defaults are used.

   LIBRARIES   RF24 by TMRh20  +  esp32 by Espressif
   BOARD       AI Thinker ESP32-CAM
   PARTITION   Huge APP (3MB No OTA)
   ============================================================ */

#include <Arduino.h>
#include <esp_camera.h>
#include <SPI.h>
#include <SD.h>
#include <RF24.h>

// ---- SD and NRF24 SHARE ONE SPI BUS ----
#define PIN_SCK      14
#define PIN_MOSI     15
#define PIN_MISO      2
#define PIN_SD_CS    13
#define PIN_NRF_CSN  12   // needs a 10k pulldown to GND (strapping pin)
#define PIN_NRF_CE    4   // shared with the flash LED - tape over it

SPIClass hspi(HSPI);
RF24 radio(PIN_NRF_CE, PIN_NRF_CSN);

const uint8_t ADDR_TX[5] = {0x11, 0x22, 0x33, 0x44, 0x55};
const uint8_t NRF_CHANNEL = 100;

// ---- defaults (overridable from holocube.cfg) ----
uint16_t cfg_aec        = 300;   // 0..1200  exposure. THE number to tune.
uint8_t  cfg_gain       = 0;     // 0..30    keep low, gain is noise
uint8_t  cfg_hi_quality = 10;    // 10..63   lower = better
uint8_t  cfg_lo_quality = 18;    // telemetry shot, keep it small
uint16_t cfg_video_sec  = 15;
uint16_t cfg_pause_sec  = 30;

#define HI_RES  FRAMESIZE_UXGA   // 1600x1200 master
#define LO_RES  FRAMESIZE_QQVGA  // 160x120   telemetry + video

// ---- packet format: 32 bytes, hardware CRC-16 does integrity ----
//   [0] type   [1] fragment   [2..31] 30 bytes of payload
#define PKT_IMG_START 0x01
#define PKT_IMG_DATA  0x02
#define PKT_IMG_END   0x03
#define PKT_VID_META  0x04
#define PKT_STATUS    0x06
#define PKT_SIZE      32
#define CHUNK         30
#define MAX_FRAGS     255
#define MAX_TX_BYTES  (MAX_FRAGS * CHUNK)   // 7650

uint16_t image_id = 0, video_id = 0;
uint32_t n_cycles = 0, n_images = 0, n_videos = 0;
uint32_t n_sd_fail = 0, n_cam_fail = 0, n_tx_skip = 0;
bool sd_ok = false, radio_ok = false;
uint32_t t0 = 0;

// ============================================================
// CRC-16-CCITT — only used end-to-end on a whole image, so the
// receiver can tell a perfect reassembly from a lossy one.
// ============================================================
uint16_t crc16(const uint8_t *d, uint32_t n) {
  uint16_t crc = 0x0000;
  for (uint32_t i = 0; i < n; i++) {
    crc ^= (uint16_t)d[i] << 8;
    for (uint8_t j = 0; j < 8; j++)
      crc = (crc & 0x8000) ? (uint16_t)((crc << 1) ^ 0x1021) : (uint16_t)(crc << 1);
  }
  return crc;
}

void send_packet(uint8_t type, uint8_t frag, const uint8_t *payload, uint8_t len) {
  if (!radio_ok) return;
  uint8_t p[PKT_SIZE];
  memset(p, 0, PKT_SIZE);
  p[0] = type;
  p[1] = frag;
  if (payload && len) memcpy(&p[2], payload, min((int)len, CHUNK));
  radio.write(p, PKT_SIZE);
}

// ============================================================
// CONFIG FILE — read once at boot, ignore anything malformed
// ============================================================
void load_config() {
  if (!sd_ok) return;
  File f = SD.open("/holocube.cfg", FILE_READ);
  if (!f) { Serial.println("[CFG] no holocube.cfg, using defaults"); return; }

  while (f.available()) {
    String line = f.readStringUntil('\n');
    line.trim();
    if (line.length() == 0 || line.startsWith("#")) continue;
    int eq = line.indexOf('=');
    if (eq < 1) continue;
    String k = line.substring(0, eq);   k.trim();
    String v = line.substring(eq + 1);  v.trim();
    long n = v.toInt();

    if      (k == "aec")        cfg_aec        = constrain(n, 0, 1200);
    else if (k == "gain")       cfg_gain       = constrain(n, 0, 30);
    else if (k == "hi_quality") cfg_hi_quality = constrain(n, 10, 63);
    else if (k == "lo_quality") cfg_lo_quality = constrain(n, 10, 63);
    else if (k == "video_sec")  cfg_video_sec  = constrain(n, 1, 120);
    else if (k == "pause_sec")  cfg_pause_sec  = constrain(n, 0, 300);
  }
  f.close();
  Serial.printf("[CFG] aec=%u gain=%u hiQ=%u loQ=%u vid=%us pause=%us\n",
                cfg_aec, cfg_gain, cfg_hi_quality, cfg_lo_quality,
                cfg_video_sec, cfg_pause_sec);
}

// ============================================================
// CAMERA
// ============================================================
void lock_exposure() {
  sensor_t *s = esp_camera_sensor_get();
  if (!s) return;
  s->set_gain_ctrl(s, 0);       // auto gain OFF
  s->set_exposure_ctrl(s, 0);   // auto exposure OFF
  s->set_aec2(s, 0);
  s->set_agc_gain(s, cfg_gain);
  s->set_aec_value(s, cfg_aec);
  s->set_brightness(s, 0);
  s->set_contrast(s, 1);        // slight lift helps the ghost read
  s->set_saturation(s, 0);
  s->set_whitebal(s, 1);
  s->set_awb_gain(s, 1);
  s->set_vflip(s, 0);
  s->set_hmirror(s, 0);
}

// Switch resolution and throw away the frames that follow.
// The sensor needs a moment; the first frames after a change
// come back with the wrong size or a bad exposure.
void set_res(framesize_t fs, uint8_t quality) {
  sensor_t *s = esp_camera_sensor_get();
  if (!s) return;
  s->set_framesize(s, fs);
  s->set_quality(s, quality);
  lock_exposure();
  delay(200);
  for (int i = 0; i < 2; i++) {
    camera_fb_t *fb = esp_camera_fb_get();
    if (fb) esp_camera_fb_return(fb);
  }
}

bool camera_init() {
  camera_config_t c;
  c.ledc_channel = LEDC_CHANNEL_0;
  c.ledc_timer   = LEDC_TIMER_0;
  c.pin_d0 = 5;  c.pin_d1 = 18; c.pin_d2 = 19; c.pin_d3 = 21;
  c.pin_d4 = 36; c.pin_d5 = 39; c.pin_d6 = 34; c.pin_d7 = 35;
  c.pin_xclk = 0; c.pin_pclk = 22; c.pin_vsync = 25; c.pin_href = 23;
  c.pin_sccb_sda = 26; c.pin_sccb_scl = 27;
  c.pin_pwdn = 32; c.pin_reset = -1;
  c.xclk_freq_hz = 20000000;
  c.pixel_format = PIXFORMAT_JPEG;
  c.frame_size   = HI_RES;
  c.jpeg_quality = cfg_hi_quality;
  c.fb_count     = 2;
  c.fb_location  = CAMERA_FB_IN_PSRAM;
  c.grab_mode    = CAMERA_GRAB_LATEST;

  if (esp_camera_init(&c) != ESP_OK) return false;
  lock_exposure();
  return true;
}

// ============================================================
// SD
// ============================================================
bool sd_write(const char *path, const uint8_t *data, size_t len) {
  if (!sd_ok) return false;
  File f = SD.open(path, FILE_WRITE);
  if (!f) { n_sd_fail++; return false; }
  size_t w = f.write(data, len);
  f.close();
  if (w != len) { n_sd_fail++; return false; }
  return true;
}

// ============================================================
// STEP 1 — video clip, low res, to the card
// ============================================================
void step_video() {
  if (!sd_ok) { Serial.println("[VID] skipped, no card"); return; }
  video_id++;

  char path[32];
  snprintf(path, sizeof(path), "/vid%04u.mjpeg", video_id);
  File f = SD.open(path, FILE_WRITE);
  if (!f) { n_sd_fail++; return; }

  uint32_t start = millis();
  uint32_t stop  = (uint32_t)cfg_video_sec * 1000UL;
  uint16_t frames = 0;

  while (millis() - start < stop) {
    camera_fb_t *fb = esp_camera_fb_get();
    if (!fb) { n_cam_fail++; break; }
    // length-prefixed frames so a reader can walk the file
    uint32_t n = fb->len;
    uint8_t hdr[4] = {(uint8_t)(n>>24),(uint8_t)(n>>16),(uint8_t)(n>>8),(uint8_t)n};
    f.write(hdr, 4);
    f.write(fb->buf, fb->len);
    esp_camera_fb_return(fb);
    frames++;
    delay(35);          // ~25 fps, leaves the card time to breathe
    yield();
  }
  f.close();

  uint8_t m[CHUNK] = {0};
  m[0] = (uint8_t)(video_id >> 8); m[1] = (uint8_t)video_id;
  m[2] = (uint8_t)(frames >> 8);   m[3] = (uint8_t)frames;
  m[4] = (uint8_t)cfg_video_sec;
  send_packet(PKT_VID_META, 0, m, CHUNK);

  n_videos++;
  Serial.printf("[VID] %s  %u frames in %us\n", path, frames, cfg_video_sec);
}

// ============================================================
// STEP 2 — high-res master photo, card only
// ============================================================
void step_master_photo() {
  set_res(HI_RES, cfg_hi_quality);

  camera_fb_t *fb = esp_camera_fb_get();
  if (!fb) { n_cam_fail++; Serial.println("[HI ] capture failed"); return; }

  image_id++;
  char path[32];
  snprintf(path, sizeof(path), "/hi%05u.jpg", image_id);
  bool saved = sd_write(path, fb->buf, fb->len);

  Serial.printf("[HI ] %s  %u bytes  sd=%d\n", path, (unsigned)fb->len, (int)saved);
  esp_camera_fb_return(fb);
  n_images++;
}

// ============================================================
// STEP 3 — low-res telemetry photo, card + radio
// ============================================================
void transmit_image(const uint8_t *jpg, uint32_t len, uint16_t id) {
  if (!radio_ok) return;

  uint32_t send_len = len;
  if (send_len > MAX_TX_BYTES) {      // truncated JPEGs still render
    send_len = MAX_TX_BYTES;          // the top of the frame
    n_tx_skip++;
  }
  uint8_t total = (uint8_t)((send_len + CHUNK - 1) / CHUNK);

  uint8_t hdr[CHUNK] = {0};
  hdr[0] = (uint8_t)(id >> 8);        hdr[1] = (uint8_t)id;
  hdr[2] = (uint8_t)(send_len >> 8);  hdr[3] = (uint8_t)send_len;
  hdr[4] = 160; hdr[5] = 120;
  hdr[6] = total;
  hdr[7] = (uint8_t)(cfg_aec >> 8);   hdr[8] = (uint8_t)cfg_aec;
  send_packet(PKT_IMG_START, 0, hdr, CHUNK);
  delay(5);

  for (uint32_t i = 0, f = 1; i < send_len; i += CHUNK, f++) {
    uint8_t n = (uint8_t)min((uint32_t)CHUNK, send_len - i);
    send_packet(PKT_IMG_DATA, (uint8_t)f, &jpg[i], n);
    delayMicroseconds(900);
    if ((f & 0x1F) == 0) yield();
  }

  uint16_t whole = crc16(jpg, send_len);
  uint8_t fin[CHUNK] = {0};
  fin[0] = (uint8_t)(id >> 8);    fin[1] = (uint8_t)id;
  fin[2] = (uint8_t)(whole >> 8); fin[3] = (uint8_t)whole;
  fin[4] = total;
  send_packet(PKT_IMG_END, total, fin, CHUNK);

  Serial.printf("[TX ] image %u  %lu bytes in %u packets\n",
                id, (unsigned long)send_len, total);
}

void step_telemetry_photo() {
  set_res(LO_RES, cfg_lo_quality);

  camera_fb_t *fb = esp_camera_fb_get();
  if (!fb) { n_cam_fail++; Serial.println("[LO ] capture failed"); return; }

  char path[32];
  snprintf(path, sizeof(path), "/lo%05u.jpg", image_id);
  sd_write(path, fb->buf, fb->len);

  transmit_image(fb->buf, fb->len, image_id);
  esp_camera_fb_return(fb);
}

// ============================================================
// STATUS — goes out with every cycle, and onto the card
// ============================================================
void send_status() {
  uint32_t up = (millis() - t0) / 1000UL;

  // Die temperature. The original ESP32's internal sensor is unreliable
  // in absolute terms - it reads the chip, not the air, and some silicon
  // returns a fixed value. Warm the board by hand on the bench: if the
  // number moves, the TREND is usable. If it's stuck, ignore this field.
  int16_t die10 = (int16_t)(temperatureRead() * 10.0f);

  uint8_t s[CHUNK] = {0};
  s[0]  = (uint8_t)(up >> 8);        s[1]  = (uint8_t)up;
  s[2]  = (uint8_t)(n_cycles >> 8);  s[3]  = (uint8_t)n_cycles;
  s[4]  = (uint8_t)(n_images >> 8);  s[5]  = (uint8_t)n_images;
  s[6]  = (uint8_t)(n_videos >> 8);  s[7]  = (uint8_t)n_videos;
  s[8]  = sd_ok ? 1 : 0;
  s[9]  = (uint8_t)(die10 >> 8);     s[10] = (uint8_t)(die10 & 0xFF);
  s[11] = (uint8_t)n_cam_fail;
  s[12] = (uint8_t)n_sd_fail;
  send_packet(PKT_STATUS, 0, s, CHUNK);

  Serial.printf("[STAT] up=%lus cyc=%lu hi=%lu vid=%lu sd=%d die=%.1fC camfail=%lu\n",
                up, n_cycles, n_images, n_videos, (int)sd_ok,
                die10 / 10.0f, n_cam_fail);

  if (sd_ok) {
    File f = SD.open("/telemetry.csv", FILE_APPEND);
    if (f) {
      f.printf("%lu,%lu,%lu,%lu,%d,%.1f,%lu,%lu\n",
               up, n_cycles, n_images, n_videos, (int)sd_ok,
               die10 / 10.0f, n_cam_fail, n_sd_fail);
      f.close();
    }
  }
}

// ============================================================
void setup() {
  Serial.begin(115200);
  delay(1500);
  Serial.println("\n\n=== HOLOCUBE / BACAR-14 Skybridge ===");

  hspi.begin(PIN_SCK, PIN_MISO, PIN_MOSI, PIN_SD_CS);

  sd_ok = SD.begin(PIN_SD_CS, hspi, 20000000);
  Serial.printf("[SD ] %s\n", sd_ok ? "ok" : "FAILED (continuing)");

  load_config();

  if (!camera_init()) Serial.println("[CAM] FATAL: init failed");
  else                Serial.println("[CAM] ok, exposure LOCKED");

  radio_ok = radio.begin(&hspi);
  if (radio_ok) {
    radio.setPALevel(RF24_PA_MAX);
    radio.setDataRate(RF24_250KBPS);
    radio.setChannel(NRF_CHANNEL);
    radio.setAutoAck(false);          // one-way link
    radio.setCRCLength(RF24_CRC_16);  // hardware integrity check
    radio.openWritingPipe(ADDR_TX);
    radio.stopListening();
  }
  Serial.printf("[NRF] %s\n", radio_ok ? "ok" : "FAILED (continuing)");

  if (sd_ok) {
    File f = SD.open("/telemetry.csv", FILE_APPEND);
    if (f) { f.println("# up_s,cycle,hi_photos,videos,sd_ok,die_C,cam_fail,sd_fail"); f.close(); }
  }

  t0 = millis();
  Serial.println("=== ARMED ===\n");
}

void loop() {
  uint32_t cycle_start = millis();
  n_cycles++;
  Serial.printf("\n--- cycle %lu ---\n", n_cycles);

  step_video();             // 1. 15 s clip -> card
  step_master_photo();      // 2. high-res  -> card
  step_telemetry_photo();   // 3. low-res   -> card + radio
  send_status();

  // sensor is already at LO_RES, so the next cycle's video
  // starts without another reconfiguration
  uint32_t elapsed = millis() - cycle_start;
  Serial.printf("--- cycle took %lus, pausing %us ---\n",
                elapsed / 1000UL, cfg_pause_sec);

  // 4. pause. delay(), not sleep: the regulator's waste heat is
  // what keeps the bay above freezing at altitude, and an idle
  // chip makes less of it.
  uint32_t pause_ms = (uint32_t)cfg_pause_sec * 1000UL;
  uint32_t t = millis();
  while (millis() - t < pause_ms) { delay(100); yield(); }
}

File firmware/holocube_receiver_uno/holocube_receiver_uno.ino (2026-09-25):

/* ============================================================
   HOLOCUBE RECEIVER  —  Arduino Uno + NRF24L01+
   Ground / relay test receiver for BACAR-14 "Skybridge"

   Packet format (32 bytes):
     [0] type   [1] fragment   [2..31] 30 bytes payload
   Integrity is the NRF24's own hardware CRC-16 — anything
   corrupt never reaches us, so there's nothing to check here.

   The Uno has 2 KB of RAM and cannot buffer an image, so it
   streams good packets out as hex and the PC reassembles.
   See holocube_rebuild.py.

   WIRING  (Uno hardware SPI)
     NRF24  CE   -> D9        MOSI -> D11
     NRF24  CSN  -> D10       MISO -> D12
     NRF24  SCK  -> D13       GND  -> GND
     NRF24  VCC  -> 3.3V   <-- NOT 5V. The module will die on 5V.

   Put 10 uF across the module's VCC/GND pins, legs short.
   Skipping that is the most common cause of "it doesn't work".
   ============================================================ */

#include <SPI.h>
#include <RF24.h>

#define PIN_CE   9
#define PIN_CSN 10
RF24 radio(PIN_CE, PIN_CSN);

const uint8_t ADDR_RX[5] = {0x11, 0x22, 0x33, 0x44, 0x55};
const uint8_t NRF_CHANNEL = 100;

#define PKT_SIZE      32
#define PKT_IMG_START 0x01
#define PKT_IMG_DATA  0x02
#define PKT_IMG_END   0x03
#define PKT_VID_META  0x04
#define PKT_STATUS    0x06

uint32_t n_rx = 0;
uint32_t t_report = 0;

void setup() {
  Serial.begin(115200);
  Serial.println(F("# HOLOCUBE receiver"));

  if (!radio.begin()) {
    Serial.println(F("# NRF24 NOT FOUND - check wiring and 3.3V"));
    while (1) { delay(1000); }
  }
  radio.setPALevel(RF24_PA_MAX);
  radio.setDataRate(RF24_250KBPS);
  radio.setChannel(NRF_CHANNEL);
  radio.setAutoAck(false);
  radio.setCRCLength(RF24_CRC_16);
  radio.openReadingPipe(1, ADDR_RX);
  radio.startListening();

  Serial.println(F("# listening on channel 100 @ 250kbps"));
  t_report = millis();
}

void loop() {
  if (radio.available()) {
    uint8_t p[PKT_SIZE];
    radio.read(p, PKT_SIZE);
    n_rx++;

    if (p[0] == PKT_STATUS) {
      uint16_t up   = ((uint16_t)p[2]  << 8) | p[3];
      uint16_t cyc  = ((uint16_t)p[4]  << 8) | p[5];
      uint16_t img  = ((uint16_t)p[6]  << 8) | p[7];
      uint16_t vid  = ((uint16_t)p[8]  << 8) | p[9];
      int16_t  die  = ((int16_t) p[11] << 8) | p[12];
      Serial.print(F("# ALIVE up="));  Serial.print(up);
      Serial.print(F("s cyc="));       Serial.print(cyc);
      Serial.print(F(" hi="));         Serial.print(img);
      Serial.print(F(" vid="));        Serial.print(vid);
      Serial.print(F(" sd="));         Serial.print(p[10]);
      Serial.print(F(" die="));        Serial.print(die / 10.0, 1);
      Serial.println(F("C"));
      return;
    }

    if (p[0] == PKT_VID_META) {
      uint16_t vid = ((uint16_t)p[2] << 8) | p[3];
      uint16_t fr  = ((uint16_t)p[4] << 8) | p[5];
      Serial.print(F("# VIDEO clip ")); Serial.print(vid);
      Serial.print(F(" - "));           Serial.print(fr);
      Serial.print(F(" frames, "));     Serial.print(p[6]);
      Serial.println(F("s, on the SD card"));
      return;
    }

    // image packets go out as hex for the PC to reassemble
    Serial.print('P');
    for (uint8_t i = 0; i < PKT_SIZE; i++) {
      if (p[i] < 16) Serial.print('0');
      Serial.print(p[i], HEX);
    }
    Serial.println();
  }

  if (millis() - t_report > 10000UL) {
    t_report = millis();
    Serial.print(F("# rx packets=")); Serial.println(n_rx);
  }
}

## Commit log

2026-08-19 feat(telemetry): implement multi-source telemetry feeds and normalization
    Introduce a comprehensive telemetry system supporting multiple external
    data sources including APRS, SondeHub, Pico Balloon, and Rotator
    hardware.
    Key changes:
    - Implement `normalizeTelemetryPayload` in `mqttService` to handle
    varying schemas and field aliases across different hardware providers.
    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
2026-08-19 feat(ui): add MQTT connection status tracking and improve typing logic
    Introduce connection state management to the ChatRoom component to track MQTT connectivity status. This includes adding visual indicators and handling 'close' and 'offline' events to update the UI ac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
    Additionally, refactor the typing indicator logic to be more resilient by supporting multiple property names for the typing state and adjusting the timeout duration.
    - Add `mqttConnected` state to track MQTT client status
    - Implement `on('close')` and `on('offline')` listeners for connection tracking
    - Add `Wifi` icon to the UI for connection status visualization
    - Update typing user logic to handle both `is_typin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
2026-08-28 fix(chat,build): resolve MQTT leaks, cleanup issues, and config typos
    - ChatRoom: end MQTT client unconditionally on unmount (was leaking
    when broker never connected), assign clientRef immediately so
    messages sent before connect reach peers, track typing timers
    per-sender to prevent pile-up and post-unmount setState, dedupe
    normalizeChatMessage() call so ids stay stable, add MQTT Last Will
    so dead tabs are removed from presence lists instantly.
    - mqttService: wrap subscribe/subscribeAlerts cleanups so they return
    void (Set.delete returned a boolean, breaking React's useEffect
    contract across telemetry components).
    - TelemetryChart: remove unused LineChart/Line imports.
    - Rename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
2026-09-25 feat(ground-station): MQTT publish in rebuild + SSTV bridge
    Add a ground-station tooling folder with the base-station Python
    scripts that bridge the NRF24 radio link and the MQTT broker the
    deployed web dashboard subscribes to.
    - holocube_rebuild.py: gains optional --mqtt HOST publisher. On every
    reassembled JPEG it publishes to bacar/skybridge14/cubeC/image with
    the same schema (bacar.nrf.image.v1) the ESP32-CAM firmware would
    send natively, so mqttService.js's _parseNrfImagePayload picks it
    up without any web-side change. STATUS packets publish to
    holocube/telemetry with the fields mqttService reads. CRCFAIL
    images never publish; PARTIAL is disk-only unless --publish-partial.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
    [holocube_rebuild.py, holocube_sstv.py]
2026-09-25 feat(hardware): add FreeCAD scripts for printed cube parts
    - hardware/holocube.py: builds all three printed parts as solids in
    FreeCAD and exports STL (print-oriented) + STEP. Run from the
    FreeCAD Python console.
    - hardware/holocube_fitcheck.py: drops dimensionally-accurate stand-ins
    for ESP32-CAM, NRF24, 18650, boost converter, and perspex panels
    into the assembly so collisions and clearances can be verified. Run
    after holocube.py.
    - hardware/README.md: how to invoke both from the FreeCAD console and
    the hardcoded OUT path in holocube.py to be aware of on other
    machines.
    Moves the two files out of the (unversioned) parent working directory
    so they're versioned alongside the f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
2026-09-25 feat(firmware): version flight, receiver, and self-test sketches
    Move the three Arduino sketches out of the (unversioned) parent working
    directory into the repo:
    - firmware/holocube_esp32cam/ — ESP32-CAM payload firmware. Runs the
    48 s cycle (video, hi-res, lo-res + NRF, pause) and streams lo-res
    frames as 32-byte NRF24 packets that ground-station/holocube_rebuild.py
    reassembles.
    - firmware/holocube_receiver_uno/ — Uno + NRF24 ground receiver that
    prints each good packet as hex on serial.
    - firmware/holocube_selftest/ — subsystem probe, flash first to isolate
    which subsystem is broken.
    - firmware/README.md: per-sketch board / partition / library
    requirements, plus the Uno-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
    [holocube_esp32cam.ino, holocube_receiver_uno.ino, holocube_selftest.ino]
2026-09-25 docs: real project README + SOLDERING + OpenSCAD source
    - README.md: replace the Base44 boilerplate (obsolete since we removed
    the SDK) with the actual BACAR Pyramid Payload project doc — mission
    intent, hardware bill, contact, wiring notes.
    - SOLDERING.md: move the assembly / soldering guide into the repo.
    - hardware/HOLOCUBE MODULAR v2.0.scad: original OpenSCAD source for the
    cube. Predecessor to the FreeCAD scripts in the same folder — kept
    for reference and because it may still be the model of record for
    some parts.
    [HOLOCUBE MODULAR v2.0.scad]
2026-09-25 feat(hardware,firmware): add battery tester, lasercut sources, ignores
    - firmware/battcaptester/BattCapTester.ino: 18650 capacity tester
    sketch. Belongs next to the flight firmware, not in an unversioned
    scratch folder.
    - hardware/battery_tester_schematic.svg: schematic for the tester.
    - hardware/lasercut/: FreeCAD sources for every laser-cut part
    (14 .FCStd files: LID, FLOOR, WALL_L/R/CAM/NRF, CAM_PLATE,
    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
    [BACAR_lasercut.FCStd, CAM_PLATE.FCStd, CAM_PLATE.dxf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]
2026-09-25 chore: rename package, rewrite AGENTS.md, drop 40 unused UI components
    - package.json: rename "base44-app" -> "skybridge14". Drop 48 unused
    dependencies that only fed the deleted shadcn components and pages
    (all @radix-ui/* not used by the six kept UI files, plus
    react-hook-form, react-day-picker, embla-carousel-react, cmdk,
    react-resizable-panels, vaul, sonner, react-hot-toast, react-leaflet,
    react-markdown, react-quill-new, next-themes, moment, lodash,
    date-fns, html2canvas, jspdf, three, framer-motion, canvas-confetti,
    zod, @hookform/resolvers, @hello-pangea/dnd, @stripe/*, input-otp).
    Verified each with grep across src/ before removal.
    - src/components/ui/: delete 40 unus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
2026-09-25 feat: SSTV tab, disable simulation fallback, honest offline state
    Simulation removal (user request: "when connect to mqtt even if it's
    offline, disable simulation"):
    - mqttService.connect(''): sit idle and emit, instead of starting the
    sim. Once the operator has chosen MQTT, an offline broker shows
    "OFFLINE" honestly rather than fabricating telemetry.
    - ConnectionSettings.jsx: drop the "Use Simulation" button and its
    handler. Only "Connect" remains.
    - TopBar.jsx: drop the 'sim' branch from the mode indicator; status is
    now LIVE MQTT or OFFLINE, no fake in-between.
    New SSTV tab (user request: "have the sstv be its own tab"):
    - New feed tab "SSTV" alongside APRS / SondeHub / Pico Ba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
    [holocube_sstv.py]
2026-09-25 feat(sstv): pivot to external audio receiver, not encoder
    Skybridge cubes do NOT emit SSTV. The tab exists to monitor external
    sources heard on the radio (pico balloons, ISS SSTV, HAMs on the pass).
    The encoder path was the wrong flow; this switches the primary tool
    and the tab framing to receive-and-record.
    - ground-station/holocube_sstv_rx.py: new. Captures audio from a
    chosen laptop input device using sounddevice, saves rolling
    60-second WAV files, and publishes sstv/status on the way. Three
    input modes:
    - default input (built-in mic)
    - --loopback: Windows WASAPI loopback of whatever's playing to
    the speakers (no cables, no Stereo Mix hack — capture an SDR
    web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
    [holocube_sstv_rx.py]
2026-09-25 feat(sstv): auto-detect via VIS header + multi-mode + Robot36/M1 decoders
    holocube_sstv_rx.py rewrite. Instead of just recording rolling WAV
    chunks, the receiver now:
    - Listens continuously via a 3-second rolling audio buffer.
    - Scans that buffer every 50 ms for the SSTV VIS start-header
    signature: 300 ms 1900 Hz leader / 10 ms 1200 Hz break /
    300 ms 1900 Hz leader / 30 ms 1200 Hz start bit / 8 × 30 ms VIS
    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
2026-09-25 feat(sstv): in-browser receiver — no laptop-side Python needed
    The SSTV tab was pointing users at a laptop-side Python script and
    MQTT broker, which defeats the point of a web app. Move the whole
    receive path into the browser: mic access via getUserMedia, decode
    via a JS port of the Python DSP, everything client-side.
    - src/lib/sstv.js: port of the VIS detector and the Robot 36 / Martin
    M1 decoders to JavaScript. Includes a numpy-style Hilbert transform
    built on an inline Cooley-Tukey FFT (no library dependency, no
    wasm), instantaneous-frequency computation, per-line frequency
    bucketing, WAV blob generation, and canvas -> PNG dataURL export.
    - src/lib/useSstvReceiver.js: React hoo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
    [holocube_sstv_rx.py]
2026-09-25 feat(sstv): broadcast decoded frames to every viewer via MQTT
    When a browser locks on and decodes an SSTV frame, it now publishes
    the result (mode, VIS code, duration, and the PNG data URL) to the
    sstv/status topic so every other viewer sees the same capture in
    their own Recent captures list.
    - mqttService.js: new publishSstvCapture(payload) — publishes to
    MQTT_TOPICS.sstvStatus (qos 0) if the client is connected. Silent
    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
2026-09-25 refactor(sstv): migrate audio capture to AudioWorkletNode
    Silences the "ScriptProcessorNode is deprecated" console warning that
    Chrome (and eventually every other browser) will log until the node is
    removed. The receiver now uses the modern AudioWorkletNode path, which
    runs in a separate real-time audio thread and posts batches to the
    main thread via MessagePort.
    - public/sstv-worklet.js: new AudioWorkletProcessor. Accumulates 2048
    mono samples (~46 ms at 44.1 kHz) into a persistent buffer, tracks
    peak amplitude, then posts the buffer with zero-copy transferable
    ownership so the audio thread doesn't have to keep the allocation
    alive after handing it off. A fresh buffer is allocated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
2026-09-28 refactor: remove HoloCube (BACAR-14C) from the deployed app
    The telemetry source for HoloCube has been decommissioned; strip the
    cube from the web app's fleet so the dashboard no longer shows an
    "Awaiting telemetry…" card that will never fill.
    - mqttService.js: drop the BACAR-14C entry from CUBE_CONFIGS and the
    matching holocube/telemetry topic from MQTT_TOPICS. Rename
    BACAR_14C_NRF_IMAGE_SCHEMA -> NRF_IMAGE_SCHEMA since the schema
    itself is generic (the parser still accepts it for any future cube).
    Remove the sim's nrf_image_only branch — it was the only consumer
    of that mode.
    Firmware, ground-station scripts, and CAD for HoloCube stay in the
    repo (firmware/holocube_esp32cam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
2026-09-28 feat(sstv): loosen VIS tolerances, debug counters, save-current, JPEG
    Three related additions after a real-world test where playing SSTV
    through speakers into the laptop mic never triggered a capture.
    - Loosen VIS detector tolerances. LEADER band widened from
    1800..2000 Hz to 1750..2050 Hz, START band from 1120..1280 Hz to
    1080..1320 Hz, VIS-bit search band widened correspondingly. Real
    acoustic capture (speaker -> room -> mic) shifts the detected
    frequencies by 50-80 Hz from spec; a clean line-in / VB-CABLE
    signal still lands well inside the loosened window.
    - Debug counters on the detector. Every leader hit, start-bit hit,
    VIS byte read (whether it matched a known mode or not)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
2026-10-15 feat(topbar): "updated Xs ago" freshness pill — spots silent-but-connected
    Adds a continuous MQTT freshness indicator next to the LIVE MQTT badge
    so operators can tell "broker is connected AND data is flowing" from
    "broker is connected but nothing is publishing". Previously those two
    states looked identical on the dashboard.
    - mqttService.js: track lastMessageAt + messageCount, bump both on
    every inbound topic (not just cube telemetry — includes APRS,
    SondeHub, Pico, Rotator, SSTV status, images). Expose
    getLastMessageAt() and getMessageCount() getters.
    - TopBar.jsx: new freshness pill — green "updated 5s ago" when the
    most recent inbound message is <30 s old, amber "updated 4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
2026-10-15 feat(sstv): "Decode WAV file" — bypass the mic to isolate audio vs decoder
    Live mic capture through a laptop speaker is lossy enough that VIS
    regularly doesn't lock, which looks identical to "the decoder is
    broken". Add a path that bypasses the microphone entirely so the
    operator can tell which half of the chain is at fault.
    - useSstvReceiver.js: new decodeFile(file) method. Reads the WAV via
    AudioContext.decodeAudioData (auto-resamples whatever the file's
    rate is to the pipeline's 44.1 kHz, auto-downmixes to mono), feeds
    it through a fresh VISDetector in the same 2048-sample chunks the
    live worklet uses, and on lock routes the picture-data slice
    through the same handleCapture p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
2026-10-15 feat: BACAR-14A inline detail (map + graphs), per-callsign feeds, grey Pico/Rotator tabs, 5s broadcast refresh
    Big UI reshape per operator request now that the fleet is one cube.
    Fleet / tabs:
    - mqttService: drop BACAR-14B (AeroLink) from CUBE_CONFIGS. Only
    BACAR-14A (LuminoStratos) remains on the dashboard.
    - Export CALLSIGN_PREFIX ('zr6ljk') and CALLSIGN_CARDS
    (['zr6ljk', 'zr6ljk-9', 'zr6ljk-20']) — the APRS/SondeHub panels
    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
2026-10-15 feat(callsigns): pin ZR6LJK + ZR6LJK-6, user-added callsigns, aprs.fi link
    Callsign set:
    - CALLSIGN_CARDS now ['zr6ljk', 'zr6ljk-6'] (was 'zr6ljk', '-9', '-20').
    - Operator can add any callsign (not just zr6ljk-*) through a text input
    in each telemetry section. Added callsigns persist to localStorage
    under bacar_user_callsigns_v1 — per-device, not shared via MQTT.
    Each user-added card gets an X button to remove it.
    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
2026-10-15 fix: downgrade react-leaflet to v4.2.1 for React 18 compatibility
    react-leaflet v5 declares react@^19 as a peer dep because it uses the
    React 19 use() hook internally. Installing it with --legacy-peer-deps
    let it get past npm, but at runtime it crashed on first render with
    "TypeError: P is not a function" (P is the minified use() reference)
    once MQTT data started arriving and the LuminaDetail component tried
    to render the Leaflet map.
    Switch to react-leaflet@^4.2.1 — the proper React 18 line, same
    MapContainer / TileLayer / Marker / Polyline / Popup API we use.
    Drops the --legacy-peer-deps workaround in the Dockerfile too.
    Verified locally: lint clean, build clean, no runtime errors.
    Co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
2026-10-15 feat(sstv): progressive live preview — image appears line-by-line
    While a frame is being received, run the mode decoder every ~500 ms on
    whatever audio has accumulated so far and show the partial image inline
    under the "Now receiving" strip. The decoder already pads short audio
    with zeros, so each tick returns a progressively more-complete frame
    (the remaining lines come back as black and fill in on the next pass).
    On the Robot 36 API question: there isn't a well-maintained public
    Robot 36 decoder on npm. pysstv is encode-only; the only mature
    decoder (slowrx) is Linux C with no WASM port. Realistic quality
    upgrades would be a WASM build of slowrx or a server-side decode
    endpoint. Both ar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
2026-10-15 feat(sstv): blind-decode mode — decode continuously from Start listening
    Adds a "Live decode" selector (off / Robot 36 / Martin M1) in the SSTV
    tab toolbar. When set, the receiver skips the VIS-header handshake
    entirely and runs the chosen mode's decoder every ~500 ms over the
    last N seconds of rolling audio (36 s for Robot 36, 114 s for
    Martin M1). The preview image renders inline the moment you hit Start
    and refreshes continuously as the sliding window moves — no need to
    wait for a VIS leader lock.
    Trade-offs vs. VIS-locked capture, so the operator picks:
    - Blind: see something immediately, even on garbage audio; the image
    represents whatever is "under the needle" at window-end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
2026-10-15 feat(sondehub): poll amateur.sondehub API directly for live telemetry
    Hooks the dashboard into the SondeHub Amateur telemetry API — the
    same backend the official tracker at amateur.sondehub.org
    (projecthorus/sondehub-amateur-tracker, MIT) consumes. No MQTT
    publisher needed on the SondeHub side; every browser pulls its own
    tracked callsigns on a 30 s schedule.
    - src/lib/sondehubApi.js: new thin client for
    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
2026-10-15 feat(chat): auto-scroll to newest message, jump button if scrolled up
    ChatRoom used to append new messages at the bottom but never scroll
    there, so the newest message was off-screen until the viewer scrolled
    down. Classic chat UX fix:
    - Attach a ref + onScroll handler to the messages container.
    - Track a stickyRef flag: true while the scrollTop is within 80 px of
    the bottom. On every new message, if sticky we snap to the bottom;
    if the viewer is deliberately reading older history (scrolled up),
    we leave their position alone.
    - When not sticky, show a floating "↓ newest" pill in the lower-right
    of the message list. Clicking it jumps to the bottom and re-sticks.
    Also runs the scrol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
2026-10-15 fix(presence): kill the chat-room duplicate publisher — one source of truth
    ChatRoom opened its own MQTT client and published its own presence
    messages to lumina/attendees with its own session_id, no location. The
    mqttService.setObserverIdentity() publisher also puts a message on the
    same topic with the mqttService session_id and the real location.
    mqttService's presenceById map keys by sessionId, so the same browser
    tab counted as two "online" users — one with location, one without —
    and the duplicate appeared the moment the user opened the chat panel
    (because that's when the ChatRoom MQTT client connected).
    Fix: ChatRoom no longer touches presence at all.
    - ChatRoom.jsx:
    - Drop M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
2026-10-15 feat(presence): reset Who's Watching history + add Clear button
    Operator backed up the 5-day log and asked for a fresh board.
    - mqttService.js: bump PRESENCE_HISTORY_KEY and PRESENCE_LAST_BACKUP_KEY
    v1 -> v2. Every viewer's existing rolling-log entries live under the
    old v1 key and are no longer read on load. The 5-min auto-refresh
    propagates this to any dashboard already open within ~5 min, so the
    reset lands everywhere without a coordinated manual refresh.
    - mqttService.clearPresenceHistory(): new method. Empties the in-memory
    log, deletes the localStorage entry, resets the last-backup timestamp
    so the auto-backup clock starts fresh, and emits so subscribers
    re-render. Does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
2026-10-23 feat(graphs): swap Recharts graphs for Plotly.js (basic bundle)
    Lumina detail graphs now use plotly.js (basic distribution — scatter
    only, ~1 MB vs the full ~4 MB build) via react-plotly.js. Keeps the
    same card wrapper and props (title/dataKey/unit/color) so no caller
    changes. Gains: native drag-to-zoom + double-click reset, crosshair
    spikelines, hover tooltips with timestamp + value, PNG snapshot
    button, spline smoothing with soft area fill.
2026-10-23 feat(graphs): add 3D flight trajectory plot (Plotly scatter3d)
    New "3D Trajectory" card between the GPS map and the time-series
    graphs. Renders every history packet with lat/lon/altitude as a
    scatter3d trace, line coloured by altitude (Viridis) so the burst
    point reads instantly. Diamond marker on peak alt, circle on latest
    fix. Drag to rotate, scroll to zoom, hover for alt/lat/lon at any
    point.
    Swaps plotly.js-basic-dist-min for the full plotly.js-dist-min bundle
    to pick up the gl3d module (needed for scatter3d). Bundle grows to
    ~1.8 MB gzipped — acceptable for the visualisation gain. The react-
    plotly.js factory wiring is unchanged.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
2026-10-23 feat(telemetry): persist full flight history (~27 h cap)
    Raises the in-memory history cap from 180 packets (~15 min) to 20 000
    and persists a slimmed-down version to localStorage so cold loads
    rebuild the full 3D trajectory + time-series graphs even when the
    gateway is offline.
    - Per-packet entry drops to the plot-relevant fields only (lat/lon/
    alt, temp/pressure/humidity, speed/vspeed/heading, battery, RSSI/
    SNR) → ~150 B each, so 20 k entries fit well under the ~5 MB
    localStorage quota.
    - Writes are debounced on a 2 s timer so a burst of packets doesn't
    thrash localStorage.
    - Quota failure path halves the stored series and retries once; if
    that also fails, in-memory data stays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
2026-10-23 feat(topbar): password-gated clear-all-data button
    Adds a trash-can icon next to the settings cog that wipes every bit
    of locally cached mission data on this browser — flight history,
    last telemetry, chat messages, presence log, user callsigns, SSTV
    history, alerts. Does not touch the broker or other viewers.
    Gate: window.prompt() asks for a password (Chr1stmasVibeBac@r), then
    a confirm() for a second yes. NOT a real security boundary — the
    password is in the shipped JS and anyone can wipe their own
    localStorage via DevTools anyway; the gate just stops accidental
    clicks.
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2026-10-23 feat(trajectory): preserve user camera + add Reset button
    The 3D trajectory used to snap back to the default angle on every
    incoming packet because each re-render passed a new layout with a
    fixed camera eye. Now wires scene.uirevision to a cameraRev counter:
    Plotly keeps the user's rotation / zoom / pan across data updates
    while uirevision is stable, and only re-applies the default camera
    when the counter changes.
    Adds a "Reset camera" button in the card header that bumps the
    counter.
    Each viewer's camera is local to their own browser (Plotly state is
    client-side) — no cross-user sync.
2026-10-23 feat(aprs): standalone 3D trajectory tabs, any callsign
    Pulls the Trajectory3D plot out of LuminaDetail into its own shared
    component so the APRS panel can use it too.
    APRS tab now has its own 3D section with per-callsign tabs:
    - Enter ANY callsign in the Add input → becomes a new tab
    - Click a tab to switch which callsign's trajectory is plotted
    - Window selector (6h/12h/24h/3d/7d) controls how much APRS history
    to pull from the SondeHub APRS-IS gateway
    - Per-callsign history fetched + cached in state, refreshed every 60 s
    - Tracked callsigns persisted in localStorage so they survive reloads
    - Each viewer's camera is local to their own browser (uirevision);
    Reset Camera button lives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
2026-10-23 feat(tabs): enable Pico Balloon + Rotator tabs with real panels
    Both tabs were previously greyed out ('telemetry source retired') —
    now live with dedicated panels.
    Pico Balloon (PicoBalloonPanel):
    - Dedicated 3D trajectory section fed by the SondeHub Amateur API
    (same wire shape as the amateur trajectory tabs). Session-local
    callsign list, 6h/12h/24h/3d/7d windows, 60 s refresh.
    - Suggestion chips (K9YA-11, KN4IUD-11, WB8ELK-7) when the list is
    empty, so new viewers have a quick way to try it.
    - Short blurb explaining pico-balloon context at the bottom.
    Rotator (RotatorPanel):
    - Reads the live rotator/telemetry MQTT topic (already ingested by
    mqttService.getRotatorTelemetry()). S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
